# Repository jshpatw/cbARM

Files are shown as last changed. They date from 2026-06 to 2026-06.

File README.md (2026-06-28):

# cbARM (Cheese Burger ARM)

A 5-DOF (Degrees of Freedom) robot arm designed for high scalability, low cost, and ease of assembly using common makerspace materials.

Copy of Chese burger(2)

## Why did i make this?

I always wanted an interactable robotic arm. But, online, the cheap ones cant lift any substancial weight and the good ones are very unaffordable. Most arms also came in fixed sizes and usally had a short range of motion. By making this prodject, I hope to adress theese 3 problems.

## Project Overview

The cbARM project aims to recreate industry-standard robot arm functionality using affordable, accessible components. By utilizing NEMA 17 motors, 3D-printed planetary gearboxes, a fully 3d printed conical stylle thrust bearing, and 2020 aluminum extrusions, this project provides a modular, affordable, and highly repairable alternative to commercial robotic systems.

## Target Features

* 5 Degrees of Freedom for full spatial maneuverability.
* Accessible build requiring no specialized machining.
* Modular design utilizing 2020 aluminum extrusions for variable arm lengths.
* Modular electronics; using female sockets soldered onto the pcb for "hot swapping" and easy electronics replacement.
* Scalable architecture for easy repair and upgrades.

## [Bill of Materials (BOM)]([url](https://github.com/jshpatw/cbARM/blob/main/BOM.csv))
u can find the bom in the repo via BOM.csv 

## Assembly and CAD Files

All STL files required for 3D printing the chassis and planetary gearboxes are available in the `/stl` directory of this repository. Refer to the pictures in journal.md portion for more complex parts and to see how I went about making things

* Recommended Material: PETG; 3 or more wall loops 20% minimum density 100% for gears and parts holding torque and gyroid pattern for structural rigidity and heat resistance (feel free to use PLA and other settings to test fitments).
* Hardware: Ensure all M3 heat-set inserts are installed prior to joining arm segments. 
* Bearings: Ensure 10x5x4mm bearings are seated with light pressure to avoid binding within 3D-printed pockets.
* Remember to practice safety when soldering parts and make sure to get extras and expect electronic defects.



Above is are pictures of the final PCB design for the prodject as of now. I reccomend using solder on female sockets to achive the electronic modularity. ensure u plug the 24V cables the right way as to not fry the board...

 The J0 objects mainly feature:
* Mounting holes for the 2020 extrution
* A vertical mount for the nema 17 42HS60
* 16:1 planetary reducers
* A 160mm 16 pin thrust bearing inspired by Logic [Planets work]([url](https://thangs.com/designer/logicalplanet/3d-model/Lazy%20Susan%20160%20v3.0-1514462))

He also has a youtube video in that link, I recommend watching his videos to better understand the mechanics and how to assemble that specific part.

 The J1 objects feature:
* A horizontal mount for the nema 17 hs 60 motor
* A 64:1 planetary gearbox
* Specialized thick gears to hendle the high torque setup
* A ring gear with a 2020 extrution mount for torque output


Above shows how the arm should look like after the 3d printed parts are assembled. (note that wires and electronics arent shown in this picture.

I made a document specially for assembly instructions at assembly guide.md in the repo for more in depth instructions and for the rest of the parts.

## Firmware and Control
 
* Status: Development in progress. 
* Firmware: To be updated.
* Control Interface: To be updated.

DISCLAIMER: the code is still physically untested so joints may move not as intended

## Future Roadmap

* Integration of Inverse Kinematics (IK) libraries.
* Development of end-effector/gripper attachments.
* Optimization of planetary gearbox backlash and tolerances.

## Extra info
* The CAD softwares used to make the prodject are KiCad and Fusion360 on education license
* Im using a p2s for prototyping and printing parts
* I also used pla to test initial fitments and tolerances
* I used old arduino code as reference and made the scripts on vs code and double checked with chatgpt
### Links & sources:
* https://thangs.com/designer/logicalplanet/3d-model/Lazy%20Susan%20160%20v3.0-1514462
* https://www.youtube.com/watch?v=S1EmJKU_IJU
* https://makerworld.com/en/models/2686085-planetary-gearbox-nema-17-1-16

## Feedback

Im currently doing everything solo so im open for advice and would appreciate feedback regarding anything in the prodject. 

## License

This project is licensed under the MIT License.

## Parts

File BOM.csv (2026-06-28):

Category | Reference | Qty | Item Name (Brand/Spec) | Notes | Unit Price (PHP) | Unit Price (USD) | Total (PHP) | Total (USD)
Electronics | A1-A7 | 7 | Pololu A4988 | Stepper Motor Driver | 100 | 1.80 | 700 | 12.60
Electronics | C1-C7 | 7 | 100uF 35V Capacitor | Electrolytic (Low ESR) | 50 | 0.90 | 350 | 6.30
Electronics | J2-J13 | 1 | Female Connector Kit | 2.54mm pitch DuPont/Jumper | 300 | 5.40 | 300 | 5.40
Electronics | J10 | 1 | Mini360 Buck Converter | Step-down (24V to 5V) | 250 | 4.50 | 250 | 4.50
Electronics | - | 1 | ESP32 WROOM-32D | 3.3V Logic MCU | 350 | 6.30 | 350 | 6.30
Electronics | J11 | 1 | 2-Pin Terminal Block | 5.00mm Pitch, 10A rated | 20 | 0.36 | 20 | 0.36
Electronics | U1, U2 | 2 | 74HC595 | 8-bit Shift Register | 40 | 0.72 | 80 | 1.44
Electronics | PSU | 1 | Mean Well 24V 15A | LRS-350-24 Switching PSU | 1,200 | 21.60 | 1,200 | 21.60
Mechanical | - | 7 | NEMA 17 (42HS60) | 1.8° step, 1.5A-2A rated | 600 | 10.80 | 4,200 | 75.60
Mechanical | - | 60 | MR105ZZ Bearings | 10x5x4mm Steel Shielded | 25 | 0.45 | 1,500 | 27.00
Mechanical | - | 10 | 6806 Bearings | 42x30x7mm Steel Shielded | 80 | 1.44 | 800 | 14.40
Mechanical | - | 100 | M3 x 10mm Screws | Socket Head Cap (Grade 12.9) | 2 | 0.04 | 200 | 3.60
Mechanical | - | 100 | M3 Brass Inserts | For PETG/Heat-set | 5 | 0.09 | 500 | 9.00
Mechanical | - | 3kg | PETG 1.75mm Filament | High-Strength Chassis | 800 | 14.40 | 2,400 | 43.20
TOTAL |  |  |  |  |  |  | 12,850 PHP | 231.30 USD

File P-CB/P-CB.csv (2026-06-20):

Reference | Qty | Value | DNP | Exclude from BOM | Exclude from Board | Footprint | Datasheet
A1,A2,A3,A4,A5,A6,A7 | 7 | Pololu_Breakout_A4988 |  |  |  | Module:Pololu_Breakout-16_15.2x20.3mm | https://www.pololu.com/product/2980/pictures
C1,C2,C3,C4,C5,C6,C7 | 7 | C_Polarized |  |  |  | Capacitor_THT:CP_Radial_D5.0mm_P2.00mm
J2,J4,J5,J6,J7,J8,J9 | 7 | Conn_01x04_Pin |  |  |  | Connector_PinHeader_2.54mm:PinHeader_1x04_P2.54mm_Vertical
J3 | 1 | Conn_01x03 |  |  |  | Connector_PinHeader_2.54mm:PinHeader_1x03_P2.54mm_Vertical
J10 | 1 | Conn_02x02_Counter_Clockwise |  |  |  | extras:Mini360_Module
J11 | 1 | Conn_01x02_Pin |  |  |  | TerminalBlock_Phoenix:TerminalBlock_Phoenix_MKDS-1,5-2_1x02_P5.00mm_Horizontal
J12,J13 | 2 | Conn_01x19 |  |  |  | Connector_PinSocket_2.54mm:PinSocket_1x19_P2.54mm_Vertical
U1,U2 | 2 | 74HC595 |  |  |  | Package_DIP:DIP-16_W7.62mm_Socket | http://www.ti.com/lit/ds/symlink/sn74hc595.pdf

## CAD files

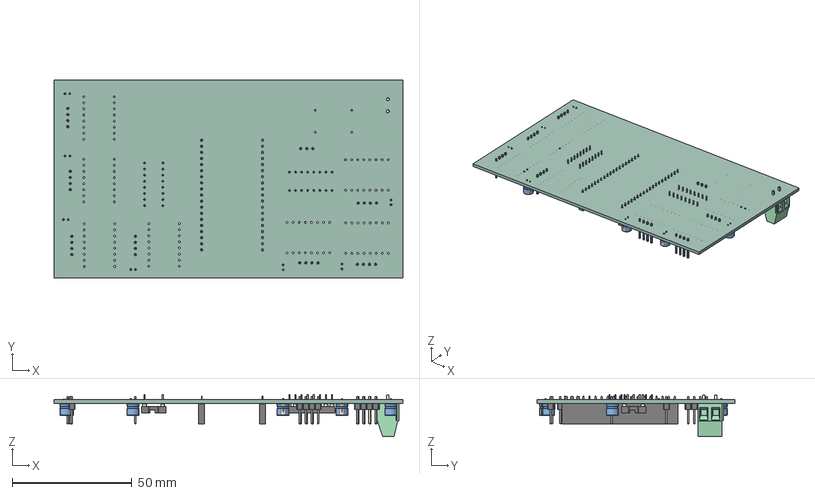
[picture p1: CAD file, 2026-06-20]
P-CB/pcbb.step
145.5 x 82.5 x 17.6 mm
CP_Radial_D50mm_P200mm x 7
PinHeader_1x04_P254mm_Vertical x 7
TerminalBlock_Phoenix_MKDS-1,5-2_1x02_P5.00mm_Horizontal
DIP_16_W762mm_Socket x 2
PinSocket_1x19_P2.54mm_Vertical x 2
PinHeader_1x03_P254mm_Vertical
P-CB_PCB

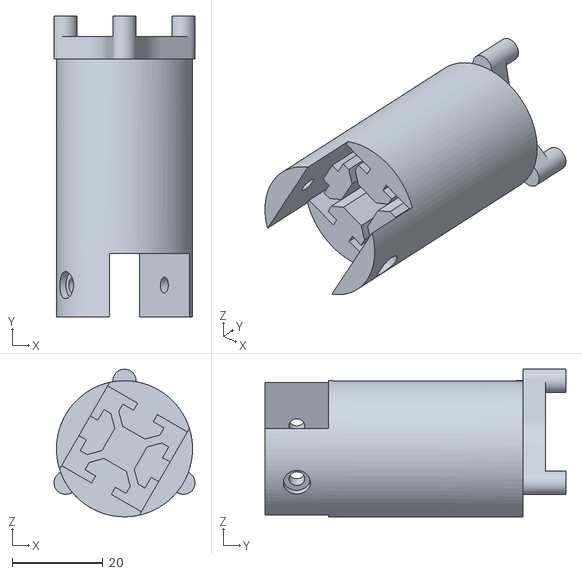
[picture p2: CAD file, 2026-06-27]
STLs/J3 2020 converter .stl
31.1 x 66.3 x 32.6

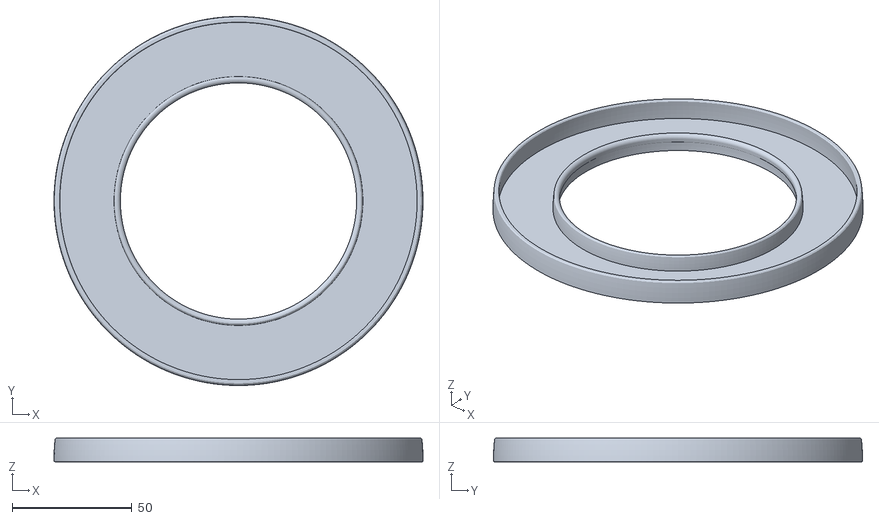
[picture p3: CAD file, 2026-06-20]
STLs/Lazy_Susan_160_v3.0/BASE.stl
154.2 x 154.2 x 10.0

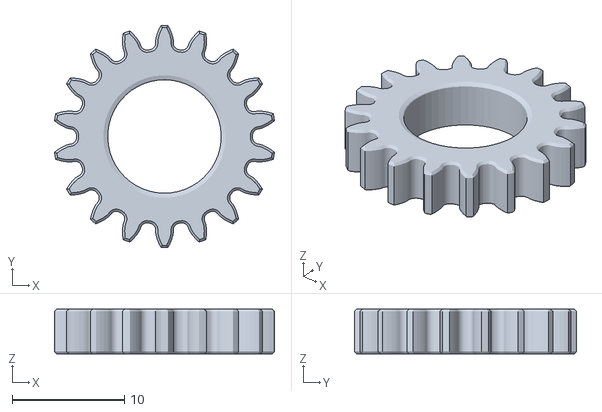
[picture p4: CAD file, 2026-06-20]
STLs/planetary+gearbox+nema_+17_stls/obj_7_gears stage2.stl_6.stl
19.6 x 19.8 x 4.00

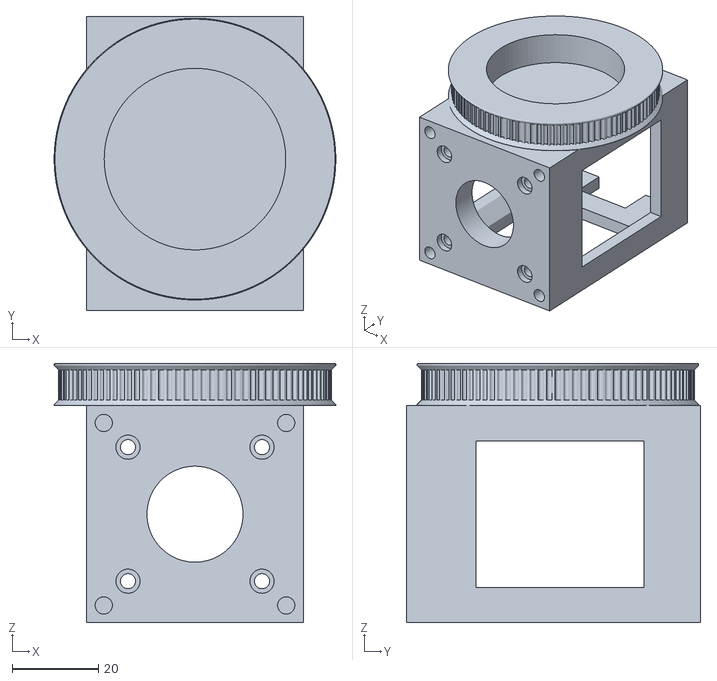
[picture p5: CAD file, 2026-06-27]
STLs/J2-3 Elbow pulley & nema 17 mount.stl
65.2 x 68.0 x 60.0

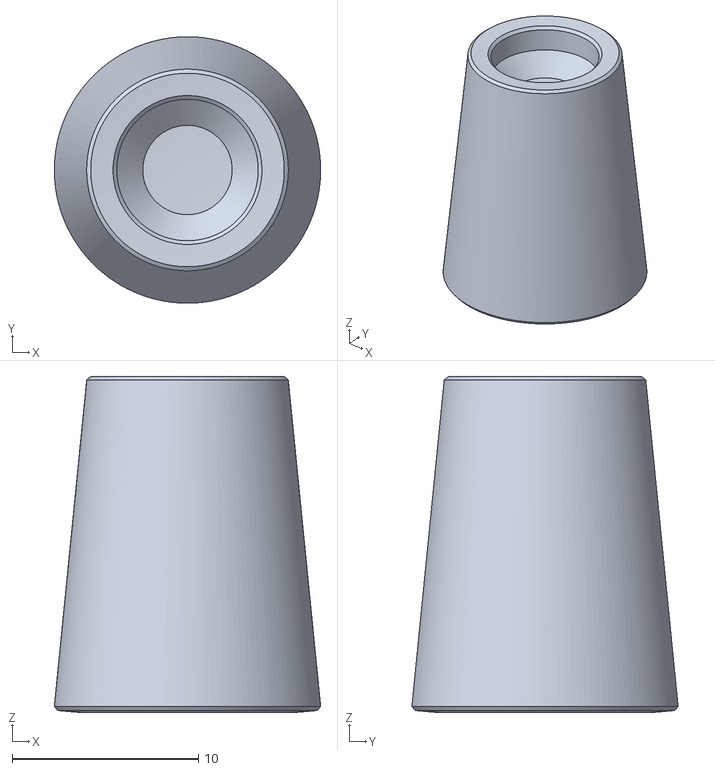
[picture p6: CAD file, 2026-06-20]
STLs/Lazy_Susan_160_v3.0/PIN (print 16).stl
14.3 x 14.3 x 18.0

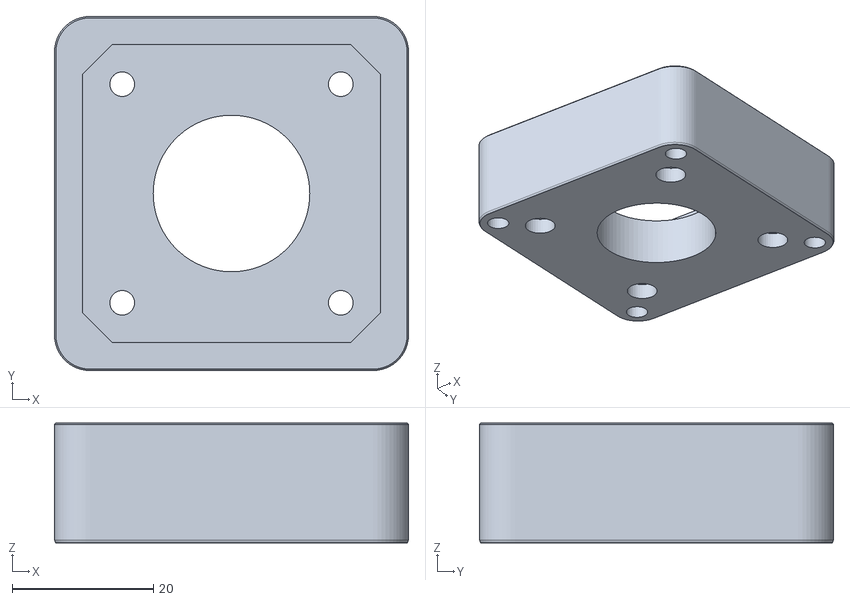
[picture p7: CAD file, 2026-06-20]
STLs/planetary+gearbox+nema_+17_stls/obj_8_stage1 and motor box.stl_4.stl
50.2 x 50.2 x 17.0

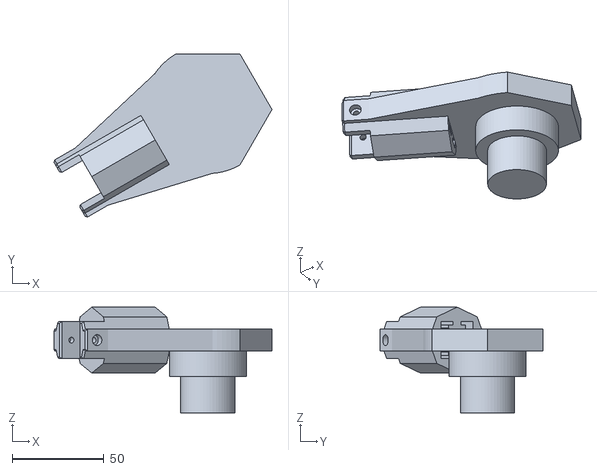
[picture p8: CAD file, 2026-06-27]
STLs/J3 2020 6806 mount.stl
119.1 x 89.1 x 57.7

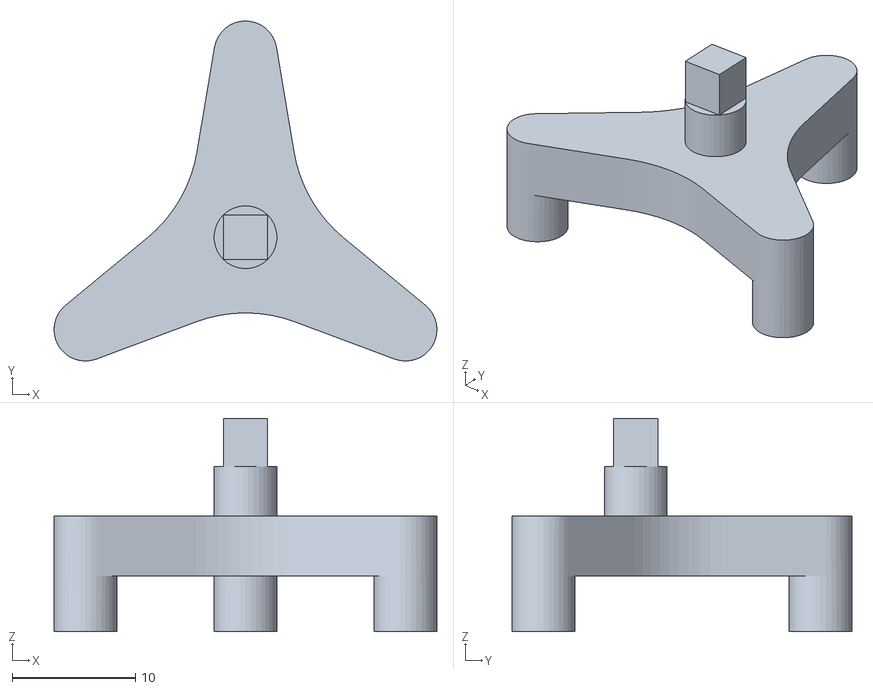
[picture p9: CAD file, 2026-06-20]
STLs/planetary+gearbox+nema_+17_stls/obj_4_gears stage2.stl_5.stl
31.1 x 27.6 x 17.3

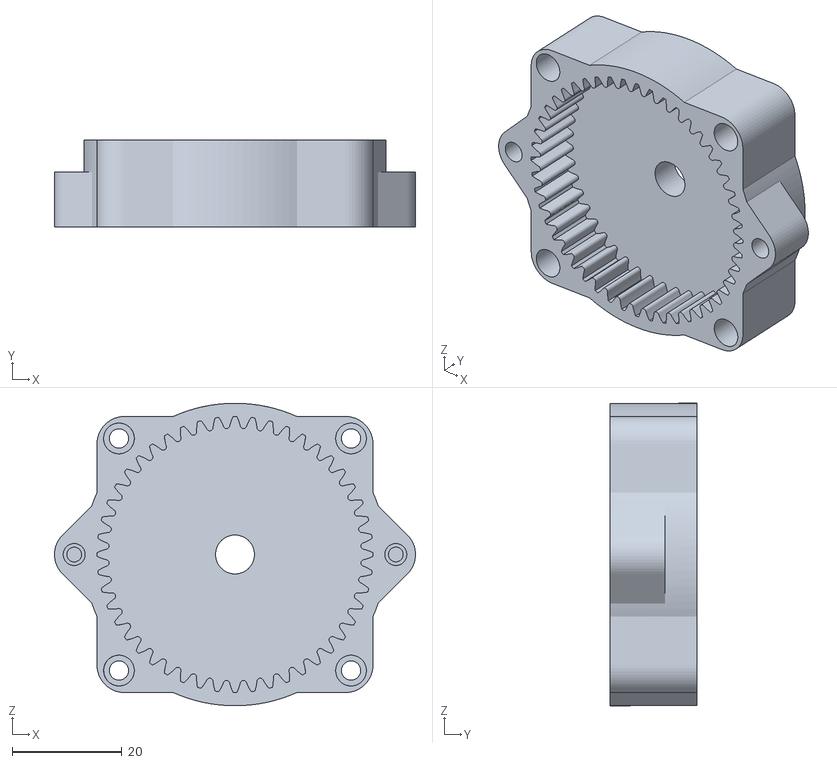
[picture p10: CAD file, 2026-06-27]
STLs/J3 Gearbox 1.stl
65.6 x 15.8 x 55.0

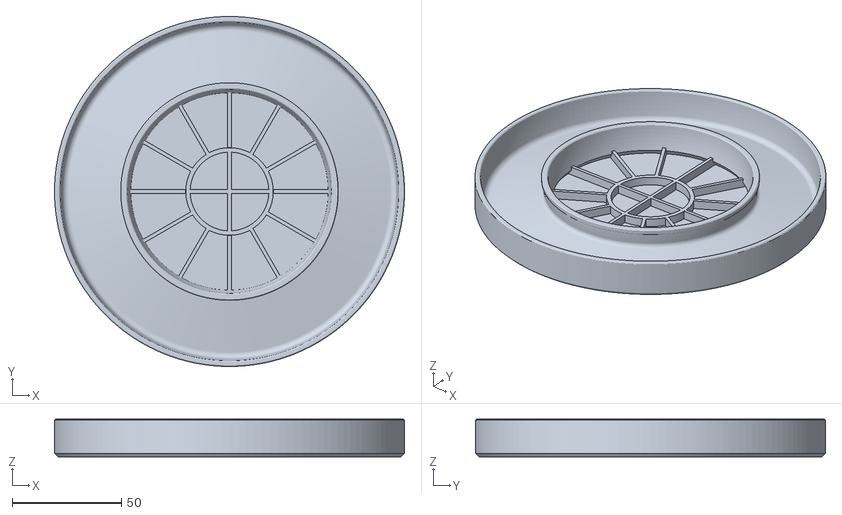
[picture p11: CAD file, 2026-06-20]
STLs/Lazy_Susan_160_v3.0/TOP Solid.stl
160.0 x 160.0 x 17.2

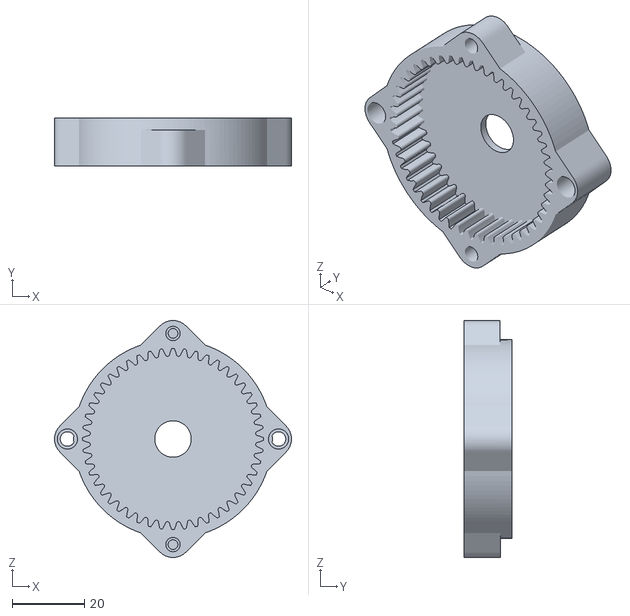
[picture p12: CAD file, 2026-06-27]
STLs/J3 Gearbox 2.stl
65.6 x 13.2 x 65.6

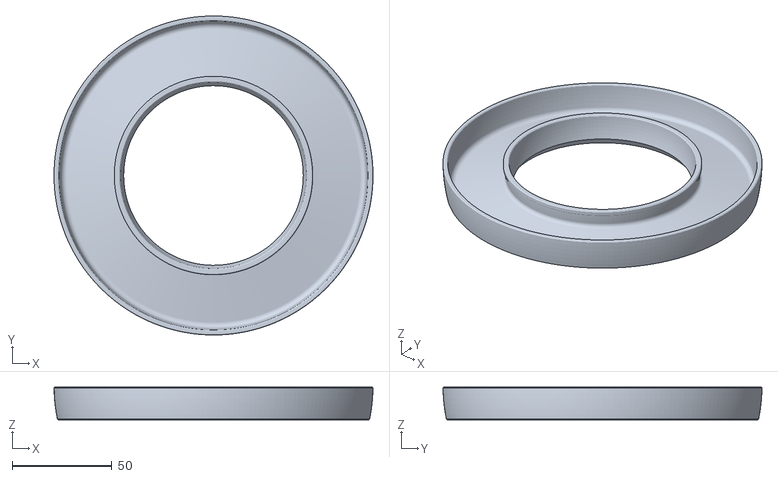
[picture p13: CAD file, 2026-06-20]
STLs/Lazy_Susan_160_v3.0/TOP Open.stl
159.8 x 159.8 x 16.4

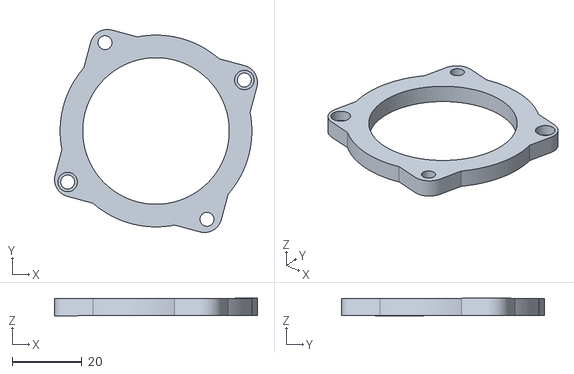
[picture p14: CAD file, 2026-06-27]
STLs/J3 Gearbox 3.stl
58.2 x 58.2 x 5.02

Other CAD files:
CAD files/Arm-Burger.step
STLs/planetary+gearbox+nema_+17_stls/obj_5_gears stage2.stl_6.stl
STLs/planetary+gearbox+nema_+17_stls/obj_2_stage 2 ring.stl_1.stl
STLs/planetary+gearbox+nema_+17_stls/obj_9_stage1 and motor box.stl_5.stl
CAD files/Arm-Burger.f3z
STLs/J1 -bottom bun- stationary mount connection.stl
STLs/J1 -onion rings- spinning gear.stl
STLs/J1 -tomatoes- stationary ring.stl
STLs/J1-2 supports.stl
STLs/J2 Converter.stl
STLs/J2 gearbox 1.stl
STLs/J2 gearbox 2.stl
STLs/J2 nema 17 mount.stl
STLs/Jn 2ndstage sungear.stl
STLs/Jn 1ststage sungear.stl
STLs/Jn converter.stl
STLs/Jn planetgear.stl
STLs/Lazy_Susan_160_v3.0/TOP open with Screw Tabs.stl
STLs/j0 -bottom bun- .stl
STLs/j0 -patty-.stl
STLs/j0 -the disposable plate- thrust bearing upper portion & j1 base.stl
STLs/j0 -the plastic tray- base and center of gravity.stl
STLs/j0 -top bun-.stl
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

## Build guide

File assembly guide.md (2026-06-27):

# Assembly Guide: cbARM PCB and Housing

This guide details the construction of the cbARM control module. 

## PCB and Electronics
To better understand, please refer to the images below:







### Component Orientation and Sockets

* **ESP32 and Driver Sockets:** Solder female headers for the ESP32 and all seven A4988 motor drivers. Using sockets prevents direct thermal damage to chips during installation and enables future replacement.
* **Driver Orientation:** Align the VMOT pin on the A4988 driver precisely with the VMOT label on the PCB. Reversed installation will cause immediate hardware failure.
* **Capacitor Polarity:** Electrolytic capacitors (C1–C7) are polarized. The positive lead must connect to the VMOT pad, and the negative lead (indicated by a stripe on the component body) must connect to the GND pad. 

### Connector Configurations

* **NEMA 17 Stepper Connections:** Use the 4-pin headers (J2–J9) for motor phase connections. Verify motor wire mapping against driver outputs before applying power.
* **Servo Connections:** The 3-pin headers are designated for servo control. Pinout is: Signal, VCC, and GND. Confirm wiring to prevent damage to the servo electronics.
* **Voltage Regulation:** Connect the Mini 360 Buck Converter (J10) so the 24V supply enters the IN pins and the 3.3V output exits the OUT pins to the logic rail. 

### PCB Mounting and Enclosure

1. **Mounting:** Align the four PCB mounting holes with the standoffs within the Case Body.
2. **Fastening:** Secure the board using M3 x 10mm screws. Tighten carefully to avoid damaging the 3D-printed standoffs.
3. **Cable Management:** Route all motor and servo cables through the case ports before closing. Ensure wiring does not put physical stress on the solder joints. 
4. **Enclosure:** Attach the Case Cap using the press-fit mechanism. Use adhesive if additional stability is required.

### Pre-Power Inspection

1. **Continuity Check:** Use a multimeter to confirm no short circuits exist between the 24V rail and the 3.3V logic rail.
2. **Voltage Verification:** Apply 24V to the input terminal (J11) and measure the output of the Mini 360. Verify it reads exactly 3.3V before inserting the ESP32 or motor drivers into their sockets.
3. **Polarity Confirmation:** Verify the positive and negative connections at the 24V terminal block (J11) to prevent reverse polarity.

## J0 Parts
the assembly of theese parts are very simplistic and dont need as complicated instructions 

* The object "STLs/j0 -the plastic tray- base and center of gravity.stl" acts as the main object for the j0 portion. On all four sides on its base are holes for 2020 aluminium extrutions. Slot the leftover 2020 extrutions from cutting the other parts and make them long enough such that they can handle the shifting weight of the whole arm. (any measurment is good as long as it works as a core target of this prodject is the users controll on how long the arm can be by simply cutting longer extrutions) I recommend atleast 120 mm coming out from all sides though.

* The object "STLs/j0 -wrapper- vertical nema 17 mount.stl" fits right into it using 4 heat set m3 screws. Together they sadwich the nema 17 42hs60 stepper motor it should look like this 

* On top of the motor mount lies the gearbox its layered kind of like a hamburger:
  1. STLs/j0 -bottom bun- .stl
  2. STLs/Jn 1ststage sungear.stl
  3. 3x STLs/Jn planetgear.stl
  4. STLs/Jn converter.stl
  5. STLs/j0 -patty-.stl
  6. STLs/Jn 2ndstage sungear.stl
  3. 3x STLs/Jn planetgear.stl
  4. STLs/Jn converter.stl
  5. STLs/j0 -top bun-.stl
 
It should look like this but ignore the bottom most part:





* To make the thrust bearing and j0 in general to work, snap fit STLs/Lazy_Susan_160_v3.0/PIN (print 16).stl and STLs/Lazy_Susan_160_v3.0/CARRIER.stl together and put them on top of STLs/j0 -the plastic tray- base and center of gravity.stl. Press fit STLs/j0 key.stl on top of the gearbox and STLs/j0 -the disposable plate- thrust bearing upper portion & j1 base.stl wich then snap fits into STLs/j0 -the plastic tray- base and center of gravity.stl

Refer to this image to better understand the thrust bearing.


In the end J0 should look like this alltogether. But ignore the gearbox on top of it...


## J1 Parts
J1 lies on top of the "STLs/j0 -the disposable plate- thrust bearing upper portion & j1 base.stl" Its also stacked like a hamburger: 
1. STLs/j1 -wrapper- nema 17 horizontal mount.stl
2. STLs/J1 -bottom bun- stationary mount connection.stl
3. STLs/Jn 1ststage sungear.stl
4. 3x STLs/Jn planetgear.stl
5. STLs/Jn converter.stl
6. STLs/J1 -tomatoes- stationary ring.stl
7. STLs/Jn  2ndstage sungear.stl
4. STLs/Jn planetgear.stl
5. STLs/Jn converter.stl
6. STLs/j1 -onions- pause print at ~12 mm .stl
7. STLs/j1 -pepper(1)- sun gear.stl (1cm, thicker gear)
8. 3x STLs/j1 -salt(3)- planet gears.stl (1cm, thicker gear)
9. STLs/J1 -onion rings- spinning gear.stl
10. 3x STLs/j1 -bun flags (3)- lockes gears in place.stl

You will have to pause "STLs/j1 -onions- pause print at ~12 mm .stl" at ~12mm and slot in the 1cm thick gears with thier bearings and then continue the print. You will then slot in the "STLs/J1 -onion rings- spinning gear.stl" such that the 1cm gears are inside it. After this, you will screw in the 3x "STLs/j1 -bun flags (3)- lockes gears in place.stl" into "STLs/j1 -onions- pause print at ~12 mm .stl" in order to keep the moving onion ring in place.

### J2 supports
Use the 6806 bearings, slot it into the 30 mm groves on  "STLs/j0 -the disposable plate- thrust bearing upper portion & j1 base.stl" and slot "STLs/J1-2 supports.stl" right into it and connect it to "STLs/J1 -onion rings- spinning gear.stl" via screws or just glue/pressfitting. Use atleast one side of this and use the second if arm will be used for more heavy torque.



## J2 parts

J2 is prettymuch slotted on top "STLs/J1 -onion rings- spinning gear.stl". On its platform it is also stacked like hamburger:

1. STLs/J2 nema 17 mount.stl
2. STLs/J2 gearbox 1.stl
3. STLs/Jn 1ststage sungear.stl
4. 3x STLs/Jn planetgear.stl
5. STLs/Jn converter.stl
6. STLs/J2 gearbox 2.stl
7. STLs/Jn  2ndstage sungear.stl
8. 3x STLs/Jn planetgear.stl
9. STLs/J2 Converter.stl
10. STLs/J2 gearbox 3.stl

Some pics of j2:


## J3 parts
J3 is connected to the main body via 2020 extrution to "STLs/J3 2020 6806 mount.stl". "STLs/J2-3 Elbow pulley & nema 17 mount.stl" Connects to this via  press fit and the 6806 bearings. After that its hamburger stacking again:

1. STLs/J2-3 Elbow pulley & nema 17 mount.stl
2. STLs/J3 Gearbox 1.stl
3. STLs/Jn 1ststage sungear.stl
4. 3x STLs/Jn planetgear.stl 
5. STLs/J3 Gearbox 2.stl
6.  STLs/Jn  2ndstage sungear.stl
7. 3x STLs/Jn planetgear.stl
8. STLs/J3 2020 converter .stl
9. STLs/J3 Gearbox 1.stl

This is what j3 looks like all together (highlight on 1. STLs/J2-3 Elbow pulley & nema 17 mount.stl)


## P.S. Keep a ruler or measuring device hand;
If a hole has a diamter of 6mm then a smaller circle, this means the hole is for m3 bolts
if the diameter is a bit smaller at about 4.5mm this is for the heat set inserts
diameter of 30mm / 42mm means "put the 6806 bearing here" 
diameter of 10mm / 5mm means "put the MR105ZZ bearing here".

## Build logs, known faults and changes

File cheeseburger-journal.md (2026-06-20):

# CheeseBurger — Journal Export

- Exported at: 2026-06-20T21:33:18Z
- Project ID: 122
- Entries: 35

## Entry 1
- ID: 6465
- Author: jshpatw
- Created At: 2026-05-10T18:21:31Z

### Content

I found existing gear drives for nema 17s
They were 4:1 planetary and were 3d printable.
I measured them and visualized them in CAD (F360)
I did the same for a 3d printable Thrust bearing.
Both mechanisms were found in youtube.
https://youtu.be/z6qtcwyZMJQ?si=9i2YCKzUBcDMl9jh
https://youtu.be/S1EmJKU_IJU?si=QGiWIuT9yBGgTerz

I plan on making the base of the arm stronger by using gear reduction for more torque and using trust bearings to minimize strain. The two will be integrated for a 3 part housing for joint 1. (bottom part & thrust bearing bottom part, nema17&4:1 planetary, and, platform for joint2&thrust bearing upper part.

Attached is a poorly drawn image of the 3 parts.
ugly sketch of plan.png

### Recording Links

- https://lookout.hackclub.com/api/media/aa4ae28d-9f7e-4f61-9ab3-4f6b11fde5d8/video.mp4

## Entry 2
- ID: 6562
- Author: jshpatw
- Created At: 2026-05-11T09:57:36Z

### Content

Did some cad work.
I integrated the base of the thrust bearing into the main base. 
The structure includes; a housing for the 42hs60 nema 17 stepper motor, space for cables, and the base of the thrust bearing on top.

Future work will include adding holes for cables to go out and holes on the bottom to support aluminum 2020 extrusions to fortify the bottom.

****


### Recording Links

- https://lookout.hackclub.com/api/media/12193d17-265c-46c0-8a19-8905efd11eae/video.mp4

## Entry 3
- ID: 6582
- Author: jshpatw
- Created At: 2026-05-11T12:50:09Z

### Content

Touched up the file.
Major updates include;
> making a bottom cavity space for 2020 extrusions
> filleting most corners and sides of the structure
> turning the file into a hybrid assembly on f360
My computer lagged a lot and while using newly learned tools in f360 like the cut, using this new tool took pretty long to actually understand.

Future work will have better wire planning and holes for threaded inserts & m3 screws.




### Recording Links

- https://lookout.hackclub.com/api/media/25e7a2d2-9a7b-4017-9dcf-92dade69e535/video.mp4

## Entry 4
- ID: 6750
- Author: jshpatw
- Created At: 2026-05-12T09:57:22Z

### Content

Did some cad on f360 for the nema 17 42hs60.
Its a housing or mounting bracket, haven't had a proper way to mount the nema 17 stepper before. In making this the steppers can be mounted on the backside too.

The cad was based off a bracket for the 4:1 planetary reducer so it can be integrated into joints for minimal parts.

I hope it works.




### Recording Links

- https://lookout.hackclub.com/api/media/d83b1270-e16f-4979-a584-94015e350c4c/video.mp4

## Entry 5
- ID: 6762
- Author: jshpatw
- Created At: 2026-05-12T11:45:10Z

### Content

I messed up in making the bracket.
I revised the mistake of making the holes too small.
I also took the chance to save my files properly and in the right places with folders. 
Most edges were curved to avoid damage on the part from wear and tear in the future.
I also took more pictures and documented measurements for the parts for easier designing in the future. 

In conclusion, this session was a future-proofing of sorts.




### Recording Links

- https://lookout.hackclub.com/api/media/b267d1b4-8d37-4fa8-b533-aad59e071185/video.mp4

## Entry 6
- ID: 6790
- Author: jshpatw
- Created At: 2026-05-12T16:13:54Z

### Content

**I am tired.**
I tried making a mesh into a solid, it became a two part body; one surface and one solid. It took me like 20 mins to even understand what a surface was. I learned how to use the surface tools in f360 to try fix it but after over 20 mins of struggle, it did not work.

The solution in the end was to just use the wrap feature in the repair options in mesh before converting the mesh into a solid. 

Before all this struggle, I made some final adjustments to the nema 17 bracket that i messed up 3 times.

Moving forward, I will have to make a platform for the shoulder joint and gear reduction on top of the hat cover thing and make it able to be controlled from below by the base joint.


_Figure 10.0, one of these bodies took a whole hour to make while the other took 45 seconds._

### Recording Links

- https://lookout.hackclub.com/api/media/bde5afa6-b451-42fb-bd10-a3bd77064750/video.mp4

## Entry 7
- ID: 6941
- Author: jshpatw
- Created At: 2026-05-13T15:40:27Z

### Content

Made the bracket work together with the base, many new ideas came to light like the possibility of just making holes in the floor of the base for cleaner wiring.

This session was not as productive but it seems like the project has become  more realistic again.
Much of the time was spent verifying metrics and measurements to insure that minimal assembly errors will happen later down the line wasting resources like filament.

I have more time than money to buy these things so I'm willing to put in the work to conserve funds.

Moving forward, I will be adding holes for heat inserts and doing the filleting properly.
also;
> bottom key actuator face to integrate to hat
> second joint housing
> limb measurements
> electronics
> sourcing a hacksaw for 2020 aluminum extrusion
> bearings





### Recording Links

- https://lookout.hackclub.com/api/media/456cec00-844b-4767-a50d-84e0f9ed2cb9/video.mp4

## Entry 8
- ID: 6959
- Author: jshpatw
- Created At: 2026-05-13T17:39:16Z

### Content

shopping, planning, research, bom work, cad modeling

made a heat insert and screw tester for future use.
found cheaper alternatives to existing items in bom

wont include insert holes in cad for now until i can test them irl


### Recording Links

- https://lookout.hackclub.com/api/media/c827ebf9-ded5-4eba-967f-2589f17708c7/video.mp4

## Entry 9
- ID: 7255
- Author: jshpatw
- Created At: 2026-05-15T13:56:57Z

### Content

I made a testing apparatus for the 2020 extrusion apparatus. I made different holes for with varying offsets or diameters?

By making this, I can standardize hole measurements and save filament later on.





### Recording Links

- https://lookout.hackclub.com/api/media/6050ed2f-1986-421e-8514-cb40c7ce2276/video.mp4

## Entry 10
- ID: 7581
- Author: jshpatw
- Created At: 2026-05-17T09:49:40Z

### Content

Planned out the hat and started printing test gearboxes. Found a lighter planetary gearbox

The upcoming steps will be complicated as i will be making use of a pulley system for the elbow joint and belt reduction for the shoulder. 

I think this will make the project more realistic but also drive up cost.

I have yet to order m3 screws and heat set inserts or do proper research on electronics although i have ideas in the BOM.

Moving forward, will;
1. - draft up a cad for horizontal nema 17 brackets
2. - test 2020 extrusion offsets
3. - further define the j1 turning mechanism
4. - find belts and pulleys
5. - redesign the base to fit new gearbox
6. - get them screws, bearings, heat inserts, and electronics
7. - beg for funding

cb12 hat super complex.png


### Recording Links

- https://lookout.hackclub.com/api/media/37578694-eb55-424c-b55c-2921acfc45ac/video.mp4

## Entry 11
- ID: 7777
- Author: jshpatw
- Created At: 2026-05-18T11:45:27Z

### Content

I found a more compact gearbox but its screw spacing seems a bit off so i plotted out more space for headset inserts and realistic screw measurement.

I also printed out the screw tester and other stuff in the background and tried assembling a few things while waiting for the net to load.
I wont cad these holes yet cuz i have to test the inserts first using that piece of plastic.









### Recording Links

- https://lookout.hackclub.com/api/media/0a871181-5d80-4521-8f52-15b2e2a36f8c/video.mp4

## Entry 12
- ID: 7811
- Author: jshpatw
- Created At: 2026-05-18T16:50:51Z

### Content

Read a few research papers on robotics & arms for inspiration. Sketched up new design for the elbow and base joint in paint im not entirely sure how the wiring will work but for shoulder ill use big small gear turning 16:1 to 64:1.

cb14 redesign of hat.png
cb13 complex joint.png
the sketches made are ugly but functional

### Recording Links

- https://lookout.hackclub.com/api/media/960942b5-15d9-4417-8ab7-9f8d94fecba6/video.mp4

## Entry 13
- ID: 8172
- Author: jshpatw
- Created At: 2026-05-20T15:52:51Z

### Content

I wanted to make my own pcb. I learned how to use kicad and stuff my first layouts basically.

it took me too long to understand this

### Recording Links

- https://lookout.hackclub.com/api/media/85d0b9c6-8d3e-4323-bacb-c8ccbb359942/video.mp4

## Entry 14
- ID: 8283
- Author: jshpatw
- Created At: 2026-05-21T09:40:41Z

### Content


learned a few more things abt kicad it take so long to wire stuff so ill try doing this label thing chatgpt is telling me about in my next works

### Recording Links

- https://lookout.hackclub.com/api/media/efcfe0cb-6258-4c22-a49c-93eed0df7dca/video.mp4

## Entry 15
- ID: 8472
- Author: jshpatw
- Created At: 2026-05-22T14:07:36Z

### Content

finished the schematic, i feel like im picking up kicad pretty well

i am proud of the wiring density and stuff

off to the pcb soon and also still waiting on the other hardware parts

### Recording Links

- https://lookout.hackclub.com/api/media/2ba6d6ef-c154-4a3c-9307-562b4e778390/video.mp4

## Entry 16
- ID: 8614
- Author: jshpatw
- Created At: 2026-05-23T07:58:53Z

### Content

very tedious footprinting went to 3 diffrent footprints on the schematic for the main esp32 wroom 32d board

i will solder female sockets ito the pins of the pcb so that electronics will be modular for future repairs



### Recording Links

- https://lookout.hackclub.com/api/media/6d379ef9-363e-4e87-b31b-6a46dd9495ae/video.mp4

## Entry 17
- ID: 8877
- Author: jshpatw
- Created At: 2026-05-24T14:41:00Z

### Content


almost done with the schematic just a lil more footprinting and effort and ill have a printable pcb

i do not look forward to the cancerous soldering that will have  to take place to complete the electronics

I cant wait!

### Recording Links

- https://lookout.hackclub.com/api/media/3560e4fa-94b5-4ff2-8f21-6fff5f504833/video.mp4

## Entry 18
- ID: 11121
- Author: jshpatw
- Created At: 2026-06-02T13:06:11Z

### Content

did a lot off fitment testing and measurement checking on cad. 
I was putting on the heatset inserts and testing the 2020 extrusion brackets f2f aswell 
.25  neg offset works for the 2020 and 
4mm diameter x 4.5mm  depth + 2.7mm diameter x 12 cm depth works for the m3 screws and heat set inserts
i also remade the brackets later on then f360 crashed but luckily it recovered my progress as i never saved the thing

i have yet to complete the kicad 
and finish the adjusting of the gear reduction device but maybe after all this i can already start doing coding?
also need to implemet new fitments and stuff to existing cads





### Recording Links

- https://lookout.hackclub.com/api/media/74fd95dc-4aba-4ed4-af00-c986868af2d5/video.mp4

## Entry 19
- ID: 11373
- Author: jshpatw
- Created At: 2026-06-03T13:17:14Z

### Content

i made a few modifications so that there would be less overhang so the bracket will be repeatable in terms of printing

i tried to fix stuff up but my cad skills are not there yet.

### Recording Links

- https://lookout.hackclub.com/api/media/e04e9171-6dda-4d86-a58c-a17adef9e53b/video.mp4
- https://lookout.hackclub.com/api/media/8abdc211-570e-4a24-8db4-02f41785fbac/video.mp4

## Entry 20
- ID: 11634
- Author: jshpatw
- Created At: 2026-06-04T15:46:27Z

### Content

more base work fixed up for the new mount for the gear reducer and nema 17 60

my fusion 360 crashed so many times.. might have to update it or something idk

also printed the new mount, came out pretty well, currently unable to share pic so maybe in next journal

### Recording Links

- https://lookout.hackclub.com/api/media/cd99c734-8445-4a05-becd-dfaa91b94211/video.mp4

## Entry 21
- ID: 12072
- Author: jshpatw
- Created At: 2026-06-06T16:19:43Z

### Content

the pcb is coming together but idk how ill wire theese things with only 2 layers it will be messy but gottu get it done so i can order the board on time... also a bit of f360 fixing 


### Recording Links

- https://lookout.hackclub.com/api/media/0ecaa5e7-ec74-43b4-94f7-85bb0dbdc047/video.mp4
- https://lookout.hackclub.com/api/media/a43b5ffe-767a-4f57-bf3e-92c8462c66d8/video.mp4

## Entry 22
- ID: 12772
- Author: jshpatw
- Created At: 2026-06-09T15:07:37Z

### Content

trying to finish the pcb before wed... need to assemble asap not done yet but i think ill get it done next time or atleast working


### Recording Links

- https://lookout.hackclub.com/api/media/b248e1a8-9d40-41ec-b3cf-cb8c850f9f82/video.mp4

## Entry 23
- ID: 12977
- Author: jshpatw
- Created At: 2026-06-10T09:36:52Z

### Content

almost done with the kicad! kicad crashed and ruined my progress but thankfully most of the progress last time was more on understanding how the pcb designer worked! 

not quite sure if this pcb is how its supposed to be but yeah im getting close i think by tomorrow i will be done!

### Recording Links

- https://lookout.hackclub.com/api/media/9d11a97c-3d5f-43dd-ac86-7e0fc04f32ac/video.mp4

## Entry 24
- ID: 13144
- Author: jshpatw
- Created At: 2026-06-11T03:18:40Z

### Content

Almost done with the pcb just need to make a ground plane and finalize things… i need to order the parts soon. my laptop died tho so idh a good picture of the pcb 

best i can do is the thumbnail of the lookout vid 
 and this 
better pics and complete pcb later today!

### Recording Links

- https://lookout.hackclub.com/api/media/66a0d454-7a45-449b-80c3-bec4842d52b4/video.mp4

## Entry 25
- ID: 13480
- Author: jshpatw
- Created At: 2026-06-12T15:54:08Z

### Content

got tripped up about how i was been designing the pcb on the wrong layer but i think im actually almost done this time ong
clutch streak save


### Recording Links

- https://lookout.hackclub.com/api/media/481e8867-3894-4692-aadf-6b9d8bfa0217/video.mp4

## Entry 26
- ID: 13677
- Author: jshpatw
- Created At: 2026-06-13T08:36:16Z

### Content


the board is done --i think. its so tuff 

this thing felt like a prodject entirely on its own and stuff so ill just include all the pics realated to its completion here for the time being before the github is done


### Recording Links

- https://lookout.hackclub.com/api/media/986eddb2-18f1-4f24-aad8-65c1fe0c1535/video.mp4

## Entry 27
- ID: 13979
- Author: jshpatw
- Created At: 2026-06-14T14:22:42Z

### Content

I believe this is the true completion of the pcb, sadly i dont have funds right now to order it but i will find some soon... 
I will now proceed with f360 again! i havent done 3d printing stuff for a while so im exited 

the biggest thing i rly did this time around was run the erc and fix up final footprints


### Recording Links

- https://lookout.hackclub.com/api/media/3e7da72a-7bee-420f-95c9-7895cbe4264d/video.mp4
- https://lookout.hackclub.com/api/media/6d1790f8-6c0e-4f72-8ec2-400e99368d48/video.mp4

## Entry 28
- ID: 14222
- Author: jshpatw
- Created At: 2026-06-15T11:35:50Z

### Content

Finished up the base and set it up to be printed, even if i don't get electronics on time imma try to get my full robot body together so i just have to plug wires and solder.



### Recording Links

- https://lookout.hackclub.com/api/media/ed320c19-a908-4f5e-bd00-569366bbdb9e/video.mp4

## Entry 29
- ID: 14546
- Author: jshpatw
- Created At: 2026-06-16T15:11:18Z

### Content

big progress i fixed up fitments on the premade gearbox to fit parts at hand also did a 24hrs print in between this but screwed up the offet fitment so i wont be able to use the 2020 extrusions to fix the base to the floor



### Recording Links

- https://lookout.hackclub.com/api/media/80cda878-9ee6-48f7-80ca-225efb16aa24/video.mp4
- https://lookout.hackclub.com/api/media/1926c0d4-2252-4775-bd3a-2c152129330e/video.mp4

## Entry 30
- ID: 14561
- Author: jshpatw
- Created At: 2026-06-16T16:08:18Z

### Content







another long session i added pics of stuff that i wasnt able to share  last journal too.. 
also im planning on making the shoulder joint 3 staged for a64:1 reduction but idk how to make it fit in the base along with the elbow belt reduction tbh

### Recording Links

- https://lookout.hackclub.com/api/media/d1152ade-f7ab-4263-bc04-c77e13b72713/video.mp4

## Entry 31
- ID: 14957
- Author: jshpatw
- Created At: 2026-06-18T08:11:04Z

### Content

pretty stumpted atm about how to make theese guys fit together without major clearance issues


ill also need a stronger converter than just a small sqare sticking out of the gearbox

### Recording Links

- https://lookout.hackclub.com/api/media/56b8fc1f-2756-4955-a022-2d622149ab4a/video.mp4

## Entry 32
- ID: 14996
- Author: jshpatw
- Created At: 2026-06-18T14:19:19Z

### Content



going to be using the surrounding ring to actuate the first joint

i will have to have s scheduled print pause and put in the gears

### Recording Links

- https://lookout.hackclub.com/api/media/4ad196f1-5b69-4823-bdf9-e5ae01190dc8/video.mp4

## Entry 33
- ID: 15027
- Author: jshpatw
- Created At: 2026-06-18T17:22:42Z

### Content


completed the j1 torque setup, now i just gottu make the mounts and smooth sailing!
(im using the containing ring gear as the thing like in cycloidial setups ive seen online from what i know it will now spin in reverse,, idt it will b a problem tho)
ps idk why my f360 keeps lagging now, it freezes everytime i even try to make a sketch...




### Recording Links

- https://lookout.hackclub.com/api/media/db84ee2b-c669-4e8d-a204-bce1bff472d3/video.mp4

## Entry 34
- ID: 15316
- Author: jshpatw
- Created At: 2026-06-19T19:13:53Z

### Content

biggest journal yet... not super proud of it as most of the time spent in this session was doing stuff i shoulda done properly before... 
in summary for this session i remade some parts, tested fittings, learned new sketching tricks and, most importantly designed the most geometrically complex looking thing i have made (also fixed my printer in between the giant lag spikes of my f360 




### Recording Links

- https://lookout.hackclub.com/api/media/1b6070c5-3bc7-4caf-a092-e3490029dd06/video.mp4

## Entry 35
- ID: 15773
- Author: jshpatw
- Created At: 2026-06-20T20:43:50Z

### Content

last log before i attempt to ship.. i finalized what i had and made the zine pdf despite my lack of editing skills


### Recording Links

- https://lookout.hackclub.com/api/media/b488e540-9c3d-47a5-8f50-e0dcf8ced620/video.mp4

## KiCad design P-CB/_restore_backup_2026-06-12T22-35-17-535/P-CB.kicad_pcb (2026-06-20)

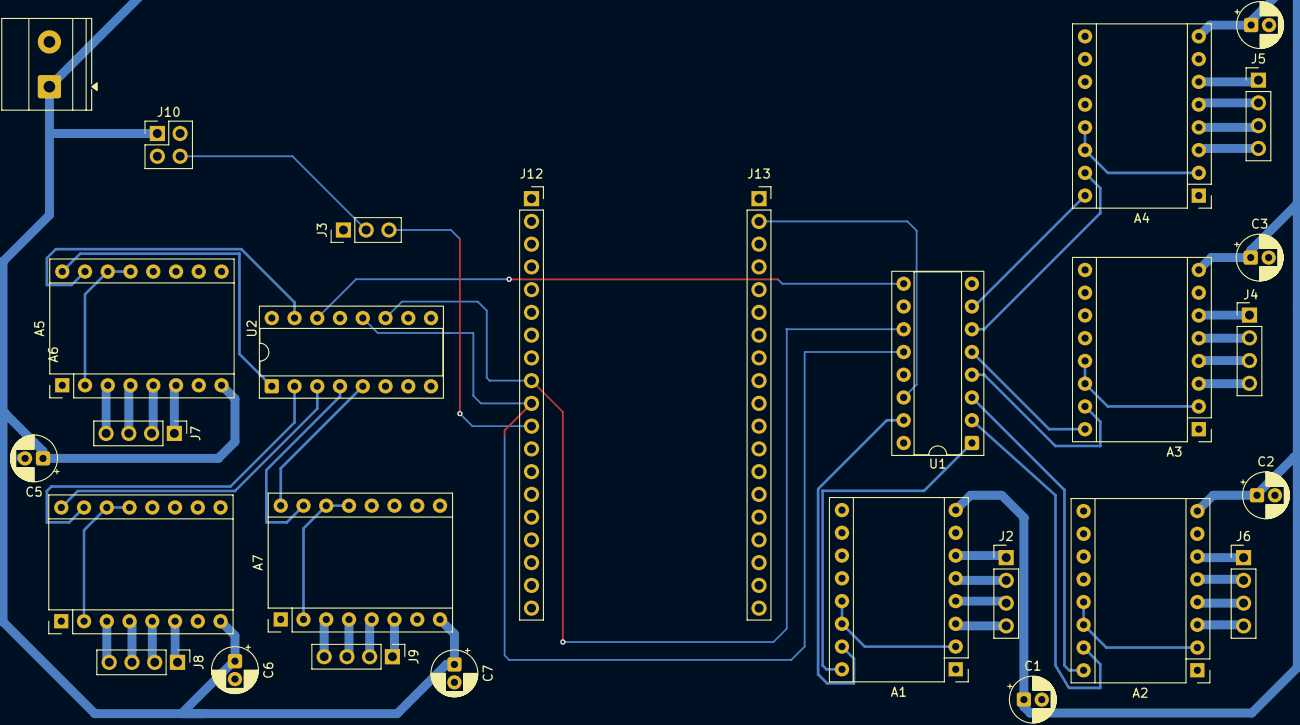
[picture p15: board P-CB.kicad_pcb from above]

Board: 2 copper layers, 28 parts (0 on the bottom side), 51 nets.

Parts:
A1, A2, A3, A4, A5, A6, A7: Pololu_Breakout_A4988; Pololu_Breakout-16_15.2x20.3mm
C1, C2, C3, C4, C5, C6, C7: C_Polarized; CP_Radial_D5.0mm_P2.00mm
J2, J4, J5, J6, J7, J8, J9: Conn_01x04_Pin; PinHeader_1x04_P2.54mm_Vertical
J3: Conn_01x03; PinHeader_1x03_P2.54mm_Vertical
J10: Conn_02x02_Counter_Clockwise; PinHeader_2x02_P2.54mm_Vertical
J11: Conn_01x02_Pin; TerminalBlock_Phoenix_MKDS-1,5-2_1x02_P5.00mm_Horizontal
J12, J13: Conn_01x19; PinSocket_1x19_P2.54mm_Vertical
U1, U2: 74HC595; DIP-16_W7.62mm_Socket

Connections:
+5V: J3.2, J10.4, J13.1
+24V: A1.8 (VMOT), A2.8 (VMOT), A3.8 (VMOT), A4.8 (VMOT), A5.8 (VMOT), A6.8 (VMOT), A7.8 (VMOT), C1.1, C2.1, C3.1, C4.1, C5.1, C6.1, C7.1, J10.1, J11.1
/3.3V_global: A1.2 (VDD), A1.13 (~RESET), A1.14 (~SLEEP), A2.2 (VDD), A2.13 (~RESET), A2.14 (~SLEEP), A3.2 (VDD), A3.13 (~RESET), A3.14 (~SLEEP), A4.2 (VDD), A4.13 (~RESET), A4.14 (~SLEEP), A5.2 (VDD), A5.13 (~RESET), A5.14 (~SLEEP), A6.2 (VDD), A6.13 (~RESET), A6.14 (~SLEEP), A7.2 (VDD), A7.13 (~RESET), A7.14 (~SLEEP), J12.1, U1.10 (~SRCLR), U1.16 (VCC), U2.10 (~SRCLR), U2.16 (VCC)
/DATA_CASCADE: U1.9 (QH'), U2.14 (SER)
/I2S_BCK: J12.9, U1.11 (SRCLK), U2.11 (SRCLK)
/I2S_DATA: J13.2, U1.14 (SER)
/I2S_LATCH: J12.10, U1.12 (RCLK), U2.12 (RCLK)
/SERVO_PWM: J3.3, J12.11
GND: A1.1 (GND), A1.7 (GND), A2.1 (GND), A2.7 (GND), A3.1 (GND), A3.7 (GND), A4.1 (GND), A4.7 (GND), A5.1 (GND), A5.7 (GND), A6.1 (GND), A6.7 (GND), A7.1 (GND), A7.7 (GND), J3.1, J10.2, J10.3, J11.2, J13.19, U1.8 (GND), U1.13 (~OE), U2.8 (GND), U2.13 (~OE)
unnamed: A1.4 (1A), J2.3
unnamed: A1.3 (1B), J2.4
unnamed: A1.5 (2A), J2.2
unnamed: A1.6 (2B), J2.1
unnamed: A1.16 (DIR), U1.1 (QB)
unnamed: A1.15 (STEP), U1.15 (QA)
unnamed: A2.4 (1A), J6.3
unnamed: A2.3 (1B), J6.4
unnamed: A2.5 (2A), J6.2
unnamed: A2.6 (2B), J6.1
unnamed: A2.16 (DIR), U1.3 (QD)
unnamed: A2.15 (STEP), U1.2 (QC)
unnamed: A3.4 (1A), J4.3
unnamed: A3.3 (1B), J4.4
unnamed: A3.5 (2A), J4.2
unnamed: A3.6 (2B), J4.1
unnamed: A3.16 (DIR), U1.5 (QF)
unnamed: A3.15 (STEP), U1.4 (QE)
unnamed: A4.4 (1A), J5.3
unnamed: A4.3 (1B), J5.4
unnamed: A4.5 (2A), J5.2
unnamed: A4.6 (2B), J5.1
unnamed: A4.16 (DIR), U1.7 (QH)
unnamed: A4.15 (STEP), U1.6 (QG)
unnamed: A5.4 (1A), J7.3
unnamed: A5.3 (1B), J7.4
unnamed: A5.5 (2A), J7.2
unnamed: A5.6 (2B), J7.1
unnamed: A5.16 (DIR), U2.1 (QB)
unnamed: A5.15 (STEP), U2.15 (QA)
unnamed: A6.4 (1A), J8.3
unnamed: A6.3 (1B), J8.4
unnamed: A6.5 (2A), J8.2
unnamed: A6.6 (2B), J8.1
unnamed: A6.16 (DIR), U2.3 (QD)
unnamed: A6.15 (STEP), U2.2 (QC)
unnamed: A7.4 (1A), J9.3
unnamed: A7.3 (1B), J9.4
unnamed: A7.5 (2A), J9.2
unnamed: A7.6 (2B), J9.1
unnamed: A7.16 (DIR), U2.5 (QF)
unnamed: A7.15 (STEP), U2.4 (QE)

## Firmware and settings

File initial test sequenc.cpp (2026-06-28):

/*
 * Robot Arm Firmware
 * Hardware: ESP32 + 2x 74HC595 Shift Registers + A4988 Drivers
 * * HARDWARE MAPPING (Based on P-CB.net):
 * ESP32 SPI: SCK=18, MOSI=23, LATCH=5
 * * Shift Register U1 (Bits 0-7):
 * - J1 (Base):    STEP=QA(0), DIR=QB(1)
 * - J2 (Shoulder): STEP=QG(6), DIR=QF(5)
 * * Shift Register U2 (Bits 8-15):
 * - J3 (Elbow):   STEP=QA(8), DIR=QB(9)
 * - J4 (Wrist):   STEP=QE(12), DIR=QF(13)
 * * Note: Drivers are in Full-Step mode (MS1/2/3 floating).
 */

#include <SPI.h>

// configs
const int LATCH_PIN = 5;
const int MOTOR_STEPS_PER_REV = 200; // Full-step mode

struct Motor {
    int stepBit;
    int dirBit;
    float gearRatio;
};

// initialize Joints
const Motor J1 = {0, 1, 64.0};
const Motor J2 = {6, 5, 32.0};
const Motor J3 = {8, 9, 16.0};
const Motor J4 = {12, 13, 16.0};

uint16_t registerState = 0;

// Convert degrees to pulses
long degreesToSteps(float degrees, float gearRatio) {
    return (long)((abs(degrees) / 360.0) * gearRatio * MOTOR_STEPS_PER_REV);
}

void updateRegisters() {
    digitalWrite(LATCH_PIN, LOW);
    SPI.transfer16(registerState);
    digitalWrite(LATCH_PIN, HIGH);
}

void moveJoint(Motor m, float degrees, bool clockwise) {
    long steps = degreesToSteps(degrees, m.gearRatio);
    
    // Set Direction
    if (clockwise) registerState |= (1 << m.dirBit);
    else registerState &= ~(1 << m.dirBit);
    updateRegisters();

    // Move with Trapezoidal Ramp
    int delayVal = 3000; 
    for (long i = 0; i < steps; i++) {
        // Simple Acceleration/Deceleration Ramp
        if (i < steps / 10 && delayVal > 1200) delayVal -= 10;
        if (i > steps * 9 / 10 && delayVal < 3000) delayVal += 10;

        registerState |= (1 << m.stepBit); 
        updateRegisters();
        delayMicroseconds(delayVal);
        
        registerState &= ~(1 << m.stepBit);
        updateRegisters();
        delayMicroseconds(delayVal);
    }
}

void setup() {
    pinMode(LATCH_PIN, OUTPUT);
    SPI.begin();
    
    // Test Sequence: 180 degrees per Joint
    moveJoint(J1, 180, true); delay(500);
    moveJoint(J2, 180, true); delay(500);
    moveJoint(J3, 180, true); delay(500);
    moveJoint(J4, 180, true); delay(500);
}

void loop() {}

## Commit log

2026-06-20 pcb stuff!
    [P-CB.csv, P-CB.kicad_pcb, P-CB.kicad_sch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]
2026-06-20 most of the stls
    [BASE.stl, J1 -bottom bun- stationary mount connection.stl, J1 -onion rings- spinning gear.stl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]
2026-06-20 Add BOM.csv with components and specifications
    [BOM.csv]
2026-06-20 Enhance README with project details and instructions
    Added detailed project overview, target features, bill of materials, assembly instructions, firmware status, future roadmap, and feedback section to README.
2026-06-20 Include PCB design images and project status update
    Added images of the final PCB design and updated project status.
2026-06-20 Update README with PCB design images and status
    Added a note about the final PCB design and firmware status.
2026-06-20 Update README with PCB and arm assembly images
    Added images of the final PCB design and 3D printed arm assembly.
2026-06-21 Update README with modular electronics details
    Added information about modular electronics and provided recommendations for soldering female sockets to achieve electronic modularity.
2026-06-22 Revise README with material and assembly details
    Updated material specifications and added details about J0 objects.
2026-06-22 Enhance README with assembly video recommendation
    Added a recommendation to watch a YouTube video for better understanding of assembly.
2026-06-25 Add assembly guide for cbARM PCB and housing
    This guide provides detailed instructions for assembling the cbARM control module, including PCB and electronics setup, connector configurations, mounting, and pre-power inspection steps.
2026-06-25 Update assembly guide.md
2026-06-25 Enhance assembly guide for J0 parts
    Expanded assembly instructions for J0 parts, including details on aluminum extrusions and motor mounting.
2026-06-25 Update assembly guide with j0 component details
    Clarified assembly instructions for j0 component, including recommendations for aluminum extrusion lengths and motor mounting.
2026-06-25 Enhance assembly guide with thrust bearing instructions
    Added detailed instructions for assembling the thrust bearing and j0 components, including references to specific STL files and images for clarity.
2026-06-25 Revise thrust bearing assembly instructions
    Updated assembly instructions for thrust bearing and j0 components, including new image references.
2026-06-27 Document J1 assembly instructions and parts list
    Added detailed instructions for assembling J1 parts, including a list of components and assembly steps.
2026-06-27 Enhance assembly guide with J2 supports and parts
    Added detailed instructions for J2 supports and parts assembly.
2026-06-27 Update BOM.csv to correct component description
    [BOM.csv]
2026-06-27 Fix typos in assembly guide for bearing sizes
2026-06-28 Add Google Drive link for CAD files
2026-06-28 Add files via upload
    firmware for testing upon assembly
2026-06-28 Fix CSV header formatting in BOM.csv
    [BOM.csv]
2026-06-28 Duplicate entries added to BOM.csv
    Added duplicate entries for various components in BOM.csv.
    [BOM.csv]
2026-06-28 Revise BOM with updated item specifications and pricing
    Updated BOM.csv to include new pricing and item details.
    [BOM.csv]
2026-06-28 Revise BOM section and add assembly guide reference
    Updated Bill of Materials section and added assembly instructions note.
2026-06-28 Add second image to README for cbARM project
    Added a second image of the cbARM robot arm to the README.
2026-06-28 Track CAD extensions with LFS and add files
    [Arm-Burger.f3z, Arm-Burger.step]
